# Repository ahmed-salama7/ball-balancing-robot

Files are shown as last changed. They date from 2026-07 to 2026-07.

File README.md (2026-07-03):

# Real-Time Ball-Balancing Robot

A closed-loop **ball-on-plate** balancing platform. A camera tracks a ball on a circular plate, and a **3-RRS parallel manipulator** driven by three servos tilts the plate to roll the ball back to the center — in real time.

A PC runs the computer-vision pipeline (OpenCV) and streams the ball's pixel coordinates over USB to an **STM32F103C8T6 "Blue Pill"**, which closes the loop with a **PID controller** and an **inverse-kinematics** solver that converts the desired plate tilt into the three servo angles.

<p align="center">
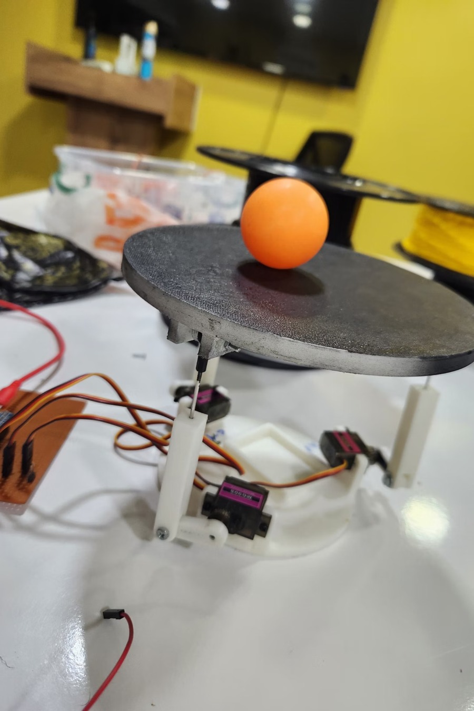
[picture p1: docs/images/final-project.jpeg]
Finished ball-balancing robot with ball centered on the plate
  
</p>

---

## Table of Contents

- [How It Works](#how-it-works)
- [Demo & Gallery](#demo--gallery)
- [Repository Structure](#repository-structure)
- [Hardware](#hardware)
  - [Bill of Materials](#bill-of-materials)
  - [Schematic & PCB](#schematic--pcb)
  - [Board Connectors](#board-connectors)
  - [STM32 Pinout](#stm32-pinout)
  - [Power](#power)
  - [KiCad Source](#kicad-source)
- [Mechanical Design](#mechanical-design)
- [Computer Vision](#computer-vision)
- [Control System (PID)](#control-system-pid)
- [Inverse Kinematics](#inverse-kinematics)
- [System Modeling](#system-modeling)
- [Getting Started](#getting-started)
- [Tuning Guide](#tuning-guide)
- [Roadmap](#roadmap)
- [Team](#team)
- [License](#license)

---

## How It Works

The system is a continuous feedback loop running at **50 Hz**:

```mermaid
flowchart LR
    CAM([USB Camera]) --> CV

    subgraph PC["PC — Python / OpenCV"]
        direction TB
        CV["Ball Detection<br/>(HoughCircles)"] --> TX["Serial TX<br/>'x,y' @ 50 Hz"]
    end

    TX -->|"USB CDC<br/>Virtual COM @ 115200"| RX

    subgraph STM["STM32F103C8T6 — Blue Pill"]
        direction TB
        RX["USB CDC RX<br/>parse x,y"] --> PID["PID Controller"]
        PID -->|"tilt slopes (nx, ny)"| IK["Inverse Kinematics<br/>(3-RRS)"]
        IK -->|"θA, θB, θC"| PWM["TIM2 PWM<br/>50 Hz"]
    end

    PWM --> SA([Servo A])
    PWM --> SB([Servo B])
    PWM --> SC([Servo C])

    SA --> PLATE[/Tilting Platform/]
    SB --> PLATE
    SC --> PLATE

    PLATE -.->|"ball rolls toward center"| CAM
```

| Stage | Where | What happens |
|---|---|---|
| **1. Detect** | PC (Python) | A webcam frame is processed with OpenCV. The ball is found with a Hough circle transform, returning its `(x, y)` pixel position. |
| **2. Transmit** | PC → MCU | The coordinates are sent as an ASCII string `"x,y\n"` over a USB CDC virtual COM port at up to 50 Hz. |
| **3. Compute error** | STM32 | The pixel error is `error = center − ball`, where the center is `(320, 240)`. |
| **4. PID** | STM32 | A discrete PID controller turns the error into a desired **platform tilt slope** `(nx, ny)`, saturated for safety. |
| **5. Inverse kinematics** | STM32 | The tilt slope and platform height are converted into three servo joint angles `(θA, θB, θC)`. |
| **6. Actuate** | STM32 → servos | Angles are mapped to PWM and written to the three servos via TIM2, tilting the plate so the ball rolls back toward center. |

---

## Demo & Gallery

| The finished robot | Assembled controller board |
|:---:|:---:|
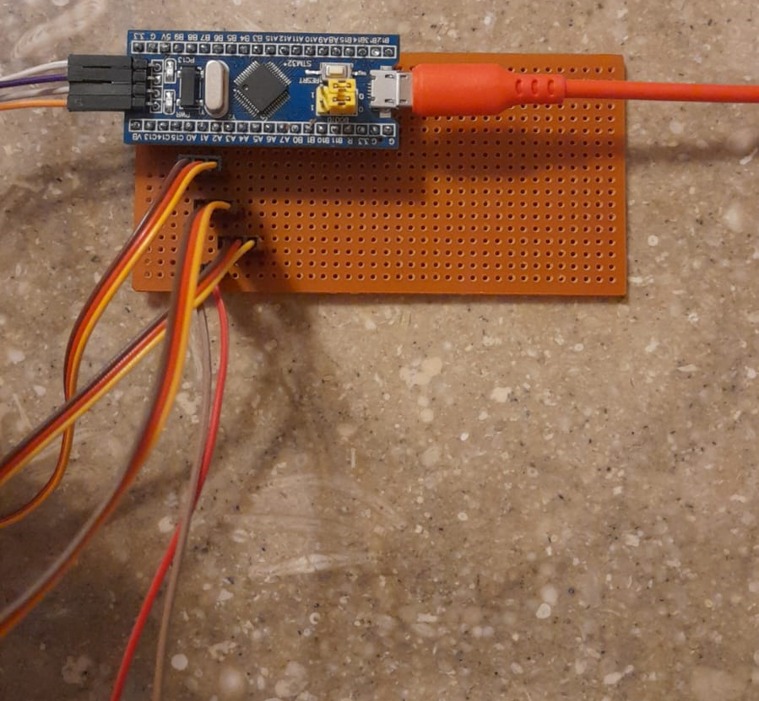
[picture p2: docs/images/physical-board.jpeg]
|  |  |

| Bench setup | CAD — isometric | CAD — side |
|:---:|:---:|:---:|
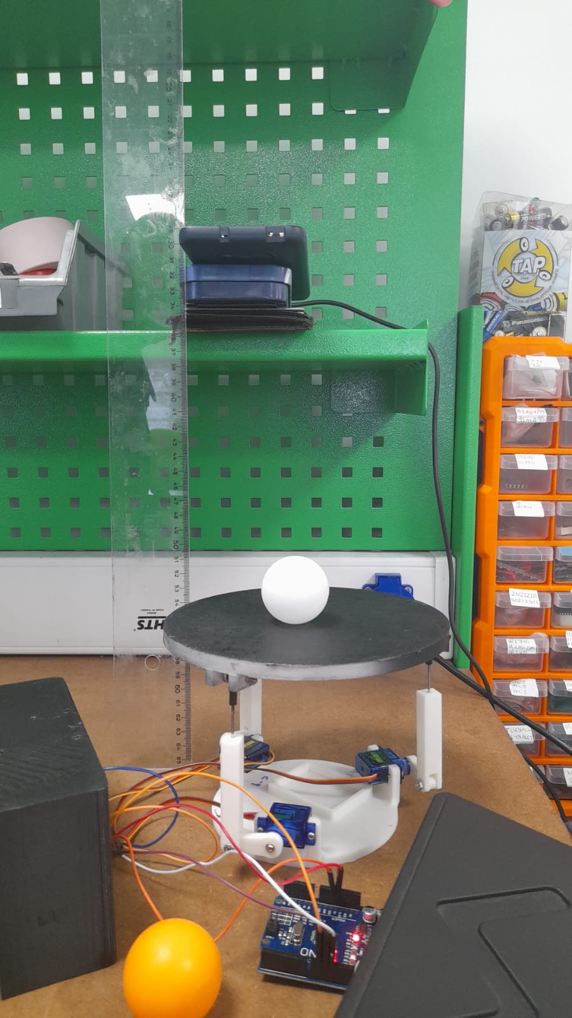
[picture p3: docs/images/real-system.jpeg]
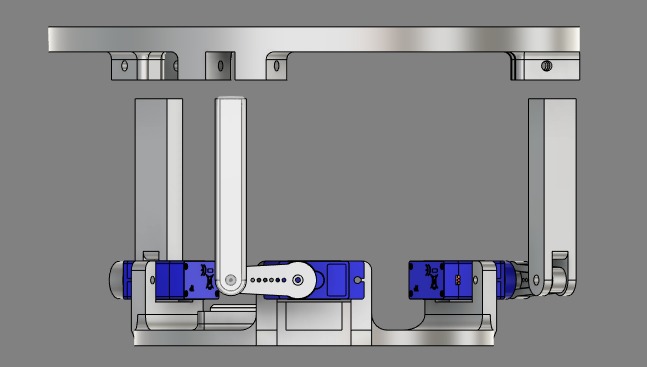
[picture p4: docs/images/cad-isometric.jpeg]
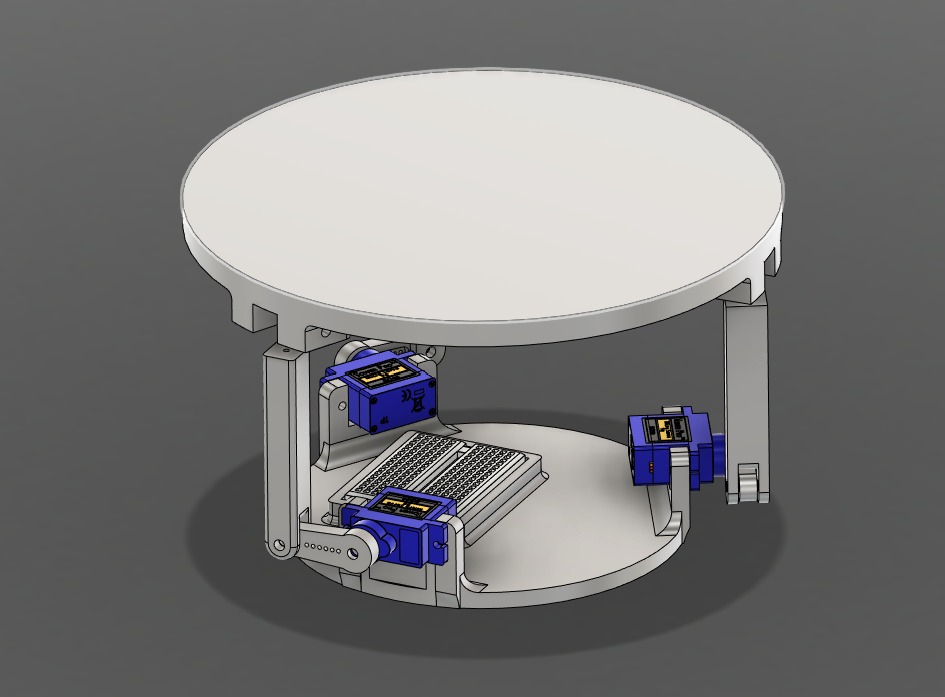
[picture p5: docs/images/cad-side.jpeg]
|  |  |  |

> A full project presentation (mechanical design, system identification, Simulink models, results) is included at
> [`docs/presentation/Real-Time-Ball-Balancing-Robot.pptx`](docs/presentation/Real-Time-Ball-Balancing-Robot.pptx).

---

## Repository Structure

```
ball-balancing-robot/
├── README.md                     ← you are here
├── LICENSE
├── .gitignore
│
├── vision/                       # PC-side computer vision (Python)
│   ├── ball_tracker.py           # main tracker: detects ball, streams coords over serial
│   ├── circle_calibration.py     # helper to align the camera with the physical plate
│   ├── requirements.txt
│   └── README.md
│
├── firmware/
│   ├── arduino/                  # Reference prototype (Arduino / STM32duino)
│   │   ├── ball_balancer/
│   │   │   ├── ball_balancer.ino # control loop: serial → PID → IK → servos
│   │   │   ├── InverseKinematics.cpp
│   │   │   └── InverseKinematics.h
│   │   └── README.md
│   │
│   └── stm32/                     # Deployed firmware (STM32CubeIDE / HAL)
│       ├── Core/                  # application code (main.c) + HAL init
│       ├── Drivers/               # CMSIS + STM32F1xx HAL drivers
│       ├── Middlewares/           # ST USB Device library
│       ├── USB_DEVICE/            # USB CDC (virtual COM) app layer
│       ├── usb_cdc.ioc            # CubeMX configuration (TIM2 PWM + USB CDC)
│       ├── STM32F103C8TX_FLASH.ld
│       ├── .cproject / .project / .mxproject
│       └── README.md
│
├── hardware/
│   ├── README.md                 # PCB, power, wiring notes
│   └── kicad/                     # editable KiCad PCB source (open the .kicad_pro)
│       ├── <project>.kicad_pro   #   project file
│       ├── <project>.kicad_sch   #   schematic
│       ├── <project>.kicad_pcb   #   board layout
│       └── <project>.kicad_prl   #   local settings
│
└── docs/
    ├── images/                   # photos, CAD renders, schematic, PCB
    └── presentation/             # full project slide deck (.pptx)
```

---

## Hardware

### Bill of Materials

| Qty | Component | Notes |
|:---:|---|---|
| 1 | **STM32F103C8T6 "Blue Pill"** | Main controller. 72 MHz Cortex-M3. |
| 3 | **9g micro servos** | Drive the three RRS legs (e.g. SG90 / MG90S class). |
| 1 | **ST-Link V2** | For flashing & SWD debugging the Blue Pill. |
| 1 | **USB webcam** | Mounted above the plate, looking straight down. |
| 1 | **External 5 V power adapter** | Powers the servos (do **not** power servos from the Blue Pill's regulator). |
| 1 | **Custom PCB** | Routes signals and 5 V power to the servos (KiCad design). |
| 1 | **Circular plate + ball** | Flat plate where the ball rolls (a standard ping-pong ball). |
| 1 | **Perfboard / protoboard** | The final build hand-wires the Blue Pill and servo headers on perfboard (see note below). |
| — | **3D-printed parts** | Base, legs, servo horns, platform mounts. |

### Schematic & PCB

| Schematic | PCB layout | PCB 3D render |
|:---:|:---:|:---:|
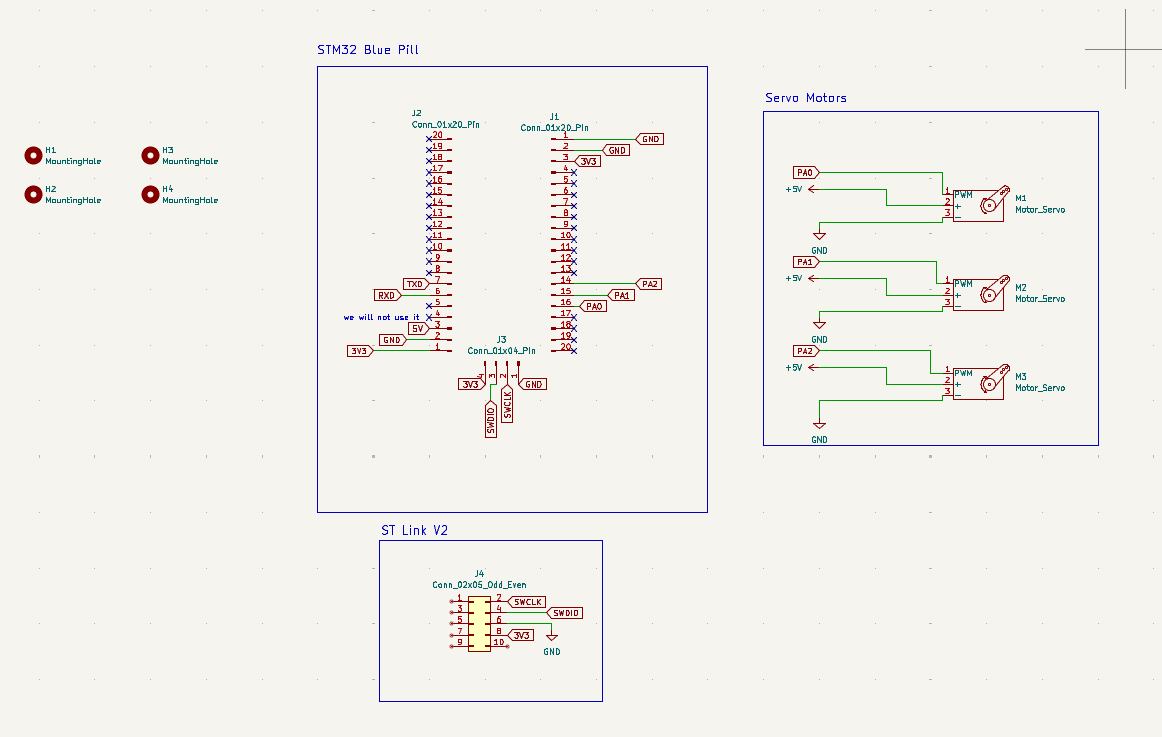
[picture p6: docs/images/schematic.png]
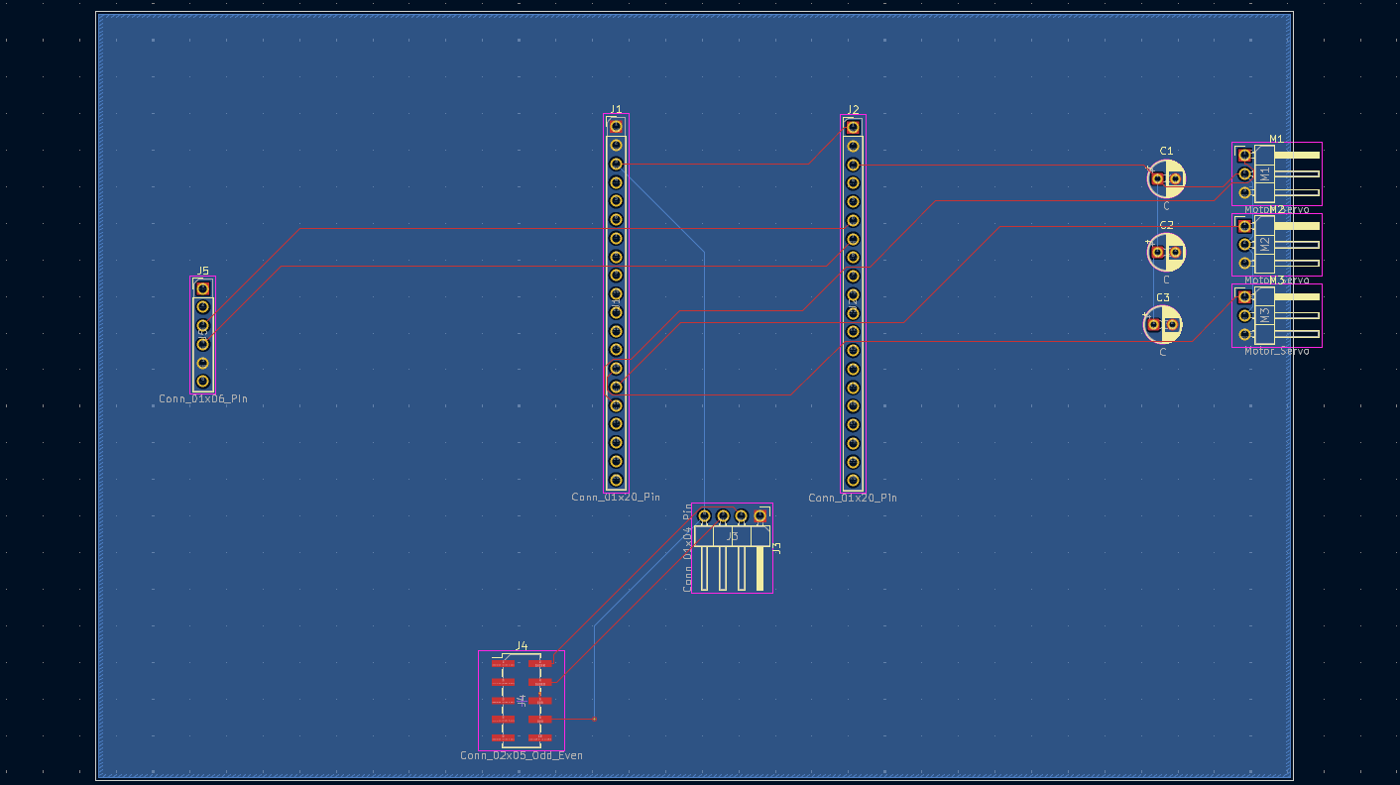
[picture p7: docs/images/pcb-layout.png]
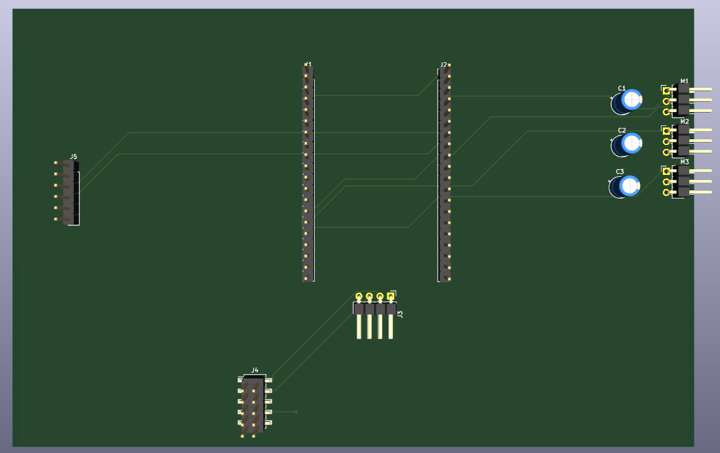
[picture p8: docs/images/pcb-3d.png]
|  |  |  |

The custom PCB acts as a carrier/breakout for the Blue Pill (`J1`, `J2`), the servo headers (`M1`–`M3`), the ST-Link SWD header (`J4`), and an auxiliary header (`J5`), with the servo signal lines and a shared external 5 V/GND rail.

> **Design vs. build.** The board above is the **KiCad design**. The **final working build** uses an STM32 Blue Pill hand-soldered onto perfboard with jumper wires out to the three servos and the ST-Link — the images below. The pin assignments are identical; only the physical routing differs.
>
> <p align="center">
>   STM32 Blue Pill hand-wired on perfboard
> </p>

### Board Connectors

The board is a carrier/breakout that fans the Blue Pill out to the three servos and the ST-Link, distributing the external 5 V servo power and a common ground.

| Ref | Role |
|-----|---|
| `J1`, `J2` | Blue Pill headers (2× 20-pin) that carry the MCU onto the board. |
| `M1`, `M2`, `M3` | Servo connectors (signal / +5 V / GND) for legs A, B, C. |
| `J4` | ST-Link V2 SWD header (SWDIO, SWCLK, 3V3, GND). |
| `J5` | Auxiliary header. |
| `C1`–`C3` | Decoupling for the servo power rail. |

### STM32 Pinout

The firmware uses **TIM2** for three hardware-PWM servo channels and the on-chip **USB peripheral** as a CDC virtual COM port.

| Pin | Peripheral / Function | Connected to |
|-----|---|---|
| **PA0** | `TIM2_CH1` — PWM | Servo **A** (Leg A / M1) signal |
| **PA1** | `TIM2_CH2` — PWM | Servo **B** (Leg B / M2) signal |
| **PA3** | `TIM2_CH4` — PWM | Servo **C** (Leg C / M3) signal |
| **PA11** | `USB_DM` | USB D− → PC |
| **PA12** | `USB_DP` | USB D+ → PC |
| **PA13** | `SWDIO` | ST-Link V2 |
| **PA14** | `SWCLK` | ST-Link V2 |
| **PC13** | GPIO output | On-board LED |
| **5V (ext.)** | Power | Servo VCC (external 5 V adapter) |
| **GND** | Ground | Common ground (PC, MCU, servos) |

**PWM timing.** TIM2 is clocked so that one count = 1 µs (`Prescaler = 72−1`) with a period of 20,000 counts (`Period = 20000−1`) → a **20 ms / 50 Hz** servo frame. Pulse widths in the ~1000–2000 µs range set servo position.

> **Note on pin numbering.** The KiCad schematic labels the servos on PA0/PA1/**PA2**, while the shipped CubeMX configuration drives them on PA0/PA1/**PA3** (TIM2 channels 1, 2, 4). The firmware is the source of truth — use **PA0 / PA1 / PA3**.

### Power

> ⚠️ **Never** power the servos from the Blue Pill's on-board regulator — three servos under load can momentarily draw amps and will brown out the MCU.

- Use a dedicated **5 V adapter** sized for your servos.
- Tie **all grounds together** — PC USB ground, MCU ground, and the servo-supply ground — so the PWM signals share a common reference.

### KiCad Source

The board's editable source lives in [`hardware/kicad/`](hardware/kicad/):

| File | What it is |
|---|---|
| `*.kicad_pro` | KiCad project file — open this one. |
| `*.kicad_sch` | Schematic. |
| `*.kicad_pcb` | PCB layout. |
| `*.kicad_prl` | Project-local settings. |

Open the `.kicad_pro` in **KiCad 7 or later** to view or edit the schematic and board, or to export gerbers for fabrication. Auto-generated backups, autosaves, and caches are excluded by `.gitignore`.

---

## Mechanical Design

The platform is a **3-RRS parallel manipulator** (each leg: a base **R**evolute joint actuated by a servo → a link → a **S**pherical joint at the moving plate; "RRS" denotes the joint chain per leg). Three legs spaced 120° apart give the plate the two tilt degrees of freedom needed to steer the ball, plus a controllable height.

The inverse-kinematics solver is parameterized by four lengths (all in **centimeters**), set in the firmware:

| Symbol | Meaning | Value (cm) |
|:---:|---|:---:|
| `d` | Base center → corner distance | 5.70 |
| `e` | Platform center → corner distance | 8.50 |
| `f` | Link 1 length (servo horn) | 3.10 |
| `g` | Link 2 length (connecting rod) | 9.66 |
| `hz` | Baseline platform height | 10.25 |

**Servo calibration** (neutral angle = plate level), from the firmware:

| | Leg A | Leg B | Leg C |
|---|:---:|:---:|:---:|
| Neutral angle | 74° | 97° | 83° |
| Direction sign | +1 | +1 | +1 |
| Safe travel limits | \[40°, 100°\] | \[40°, 100°\] | \[40°, 100°\] |

> Design goals: a stiff plate, **known neutral geometry** so the IK baseline is exact, and conservative servo travel limits so the mechanism can never drive itself into a hard stop.

---

## Computer Vision

The vision script ([`vision/ball_tracker.py`](vision/ball_tracker.py)) detects the ball and streams its position. The pipeline:

1. **Pre-process** — convert the frame to grayscale and apply a 9×9 Gaussian blur to suppress noise.
2. **Detect** — run a Hough circle transform (`cv2.HoughCircles`) to find circular candidates within a radius band.
3. **Validate** — for the white ball, the mean brightness *inside* each candidate circle is checked, rejecting non-ball circles. _(An alternative HSV color-threshold path can be used for a colored ball — see the slide deck.)_
4. **Overlay & calibrate** — a fixed reference circle is drawn at the image center `(320, 240)` so the camera frame can be physically aligned with the plate. Use [`circle_calibration.py`](vision/circle_calibration.py) to do this alignment.
5. **Transmit** — when the ball is found, the script sends `"x,y\n"` over the serial port (`COM11` @ 115200 by default). A status overlay shows the live connection state and detected pixel coordinates.

> **Set your serial port** at the top of `ball_tracker.py` (`serial_port = "COM11"`). On Linux/macOS this looks like `/dev/ttyACM0` or `/dev/tty.usbmodemXXXX`.

---

## Control System (PID)

The controller runs on a fixed sample time of $\Delta t = 20\ \text{ms}$ (50 Hz). The error is the offset of the ball from the image center, computed independently on each axis:

$$
e_x = c_x - b_x, \qquad e_y = c_y - b_y
$$

where $(c_x, c_y) = (320, 240)$ px is the target center and $(b_x, b_y)$ is the detected ball position.

A discrete PID is evaluated per axis, using **trapezoidal integration**:

$$
I_k = I_{k-1} + \left(e_k + e_{k-1}\right)\,\Delta t
$$

$$
D_k = \frac{e_k - e_{k-1}}{\Delta t}
$$

$$
u_k = K_p\, e_k + K_i\, I_k + K_d\, D_k
$$

The output $u_k$ is the **commanded plate tilt slope** $(n_x, n_y)$, clamped to a safe range to bound how far the plate can tilt:

$$
u_k \in \left[-s_{\max},\ +s_{\max}\right], \qquad s_{\max} = 0.6
$$

If no fresh coordinate arrives within ~500 ms, the controller commands the plate flat as a failsafe.

**Gains.** The PID gains were tuned iteratively; the value of starting from a small proportional gain and adding derivative damping is documented inline in the firmware. They are exposed as plain constants (`kp`, `ki`, `kd`) so you can re-tune for your own servos, plate friction, and camera latency — see the [Tuning Guide](#tuning-guide).

---

## Inverse Kinematics

Inverse kinematics converts the **desired plate pose** — a unit normal vector $\hat{n} = (n_x, n_y, n_z)$ and a height $h_z$ — into the **servo angle required for each leg**.

For each leg the solver evaluates a closed-form expression (derived from the leg geometry $d, e, f, g$) and returns the joint angle $\theta$:

$$
\theta_{\text{leg}} = \texttt{machine.theta}(\text{leg},\ h_z,\ n_x,\ n_y)
$$

The geometric angle is then mapped to a servo command using the per-leg neutral and direction calibration:

$$
\theta_{\text{servo}} = \theta_{\text{neutral}} + s \cdot \mathrm{round}\!\left(\theta - \theta_0\right)
$$

where $\theta_0$ is the baseline angle for a perfectly level plate (computed once at startup) and $s \in \{-1, +1\}$ sets the rotation direction. Each result is finally constrained to the safe travel limits before being written to the servo.

**End-to-end signal flow:**

$$
\underbrace{(b_x, b_y)}_{\text{pixels}} \;\xrightarrow{\text{PID}}\; \underbrace{(n_x, n_y)}_{\text{tilt slopes}} \;\xrightarrow{\text{IK}}\; \underbrace{(\theta_A, \theta_B, \theta_C)}_{\text{joint angles}} \;\xrightarrow{\text{map + PWM}}\; \text{servos}
$$

The full derivation lives in [`InverseKinematics.cpp`](firmware/arduino/ball_balancer/InverseKinematics.cpp).

---

## System Modeling

Beyond hand-tuning, the servos were characterized to enable model-based control design (see the slide deck for figures):

- **Data collection** — the servo's built-in position feedback was logged as `(time [ms], commanded angle [deg], measured angle [deg])`.
- **System identification** — a black-box fit produced a transfer function (settling-time / `Ts`) model of the servo response.
- **Simulink** — the closed loop was modeled both *without* and *with* the inverse-kinematics block, and the step responses were compared against the physical system.

---

## Getting Started

### 1. Vision (PC)

```bash
cd vision
pip install -r requirements.txt
# Edit ball_tracker.py and set serial_port to your board's COM/tty port
python ball_tracker.py
```

A window opens showing the camera feed, the reference circle, the detection, and an `STM: Connected/Disconnected` overlay. Press **`q`** or **`Esc`** to quit. Use `circle_calibration.py` first if you need to physically align the camera with the plate.

### 2. Firmware — STM32 (recommended / deployed)

1. Open **STM32CubeIDE** → *File ▸ Open Projects from File System…* → select `firmware/stm32/`.
2. (Optional) Open `usb_cdc.ioc` in CubeMX to review the TIM2 + USB CDC configuration.
3. Build, connect the **ST-Link V2** to the SWD header, and flash.
4. The board enumerates as a USB **Virtual COM Port** — note the port number and put it in `ball_tracker.py`.

> ⚠️ **Before this builds**, the generated source folders (`Core/`, `Drivers/`, `Middlewares/`, `USB_DEVICE/`) must be present. See **[`firmware/stm32/README.md`](firmware/stm32/README.md)** — those folders are *not* committed here yet, and the README explains exactly how to add them.

### 3. Firmware — Arduino (reference prototype)

```text
Open firmware/arduino/ball_balancer/ball_balancer.ino in the Arduino IDE
→ install the Servo library
→ select your board, then upload
```

This sketch contains the same control logic (PID + inverse kinematics) and is the easiest way to read and understand the algorithm. See [`firmware/arduino/README.md`](firmware/arduino/README.md).

---

## Tuning Guide

Re-tune for your own hardware in this order:

1. **Camera alignment & center.** Run `circle_calibration.py`. Make sure the reference circle is concentric with the plate and `(320, 240)` is the true target. A miscalibrated center is the #1 cause of a ball that "parks" off-center.
2. **Servo neutrals.** With the plate empty, adjust `servoNeutralA/B/C` until the plate is dead level. The IK baseline depends on this.
3. **Proportional gain `kp`.** Start small. Increase until the ball is actively pushed toward center, then back off just before it oscillates.
4. **Derivative gain `kd`.** Add a little to damp overshoot and settle the ball faster.
5. **Integral gain `ki`.** Add a *very* small amount only if the ball consistently settles slightly off-center. Too much integral causes slow oscillation/wind-up.
6. **Safety.** Keep `maxSlope` and the servo travel limits conservative until the loop is stable.

---

## Roadmap

Ideas for extending the project:

- [ ] Trajectory tracking (drive the ball along a circle/figure-8, not just to center)
- [ ] On-board vision (move detection to an MCU/SBC to remove the PC)
- [ ] Auto-tuning or model-based (LQR/state-feedback) control using the identified servo model
- [ ] Latency compensation / ball-velocity estimation (Kalman filter)
- [ ] Publish the KiCad source and 3D-printable STL files

---

## Team

**Team 11**

| Discipline | Member(s) |
|---|---|
| Control | Mohamed Haroun, Abdulrahman Alabed |
| Computer Vision | Taqi Aldeen |
| Electronics | Ahmed Salama |
| Mechanical | Salah Hamwi |
| Embedded Systems | Abdelaziz Hassan |

---

## License

Released under the **MIT License** — see [`LICENSE`](LICENSE).

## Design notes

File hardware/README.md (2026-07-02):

# Hardware

The custom PCB and wiring for the ball-balancing platform.

| Schematic | PCB layout | 3D render |
|:---:|:---:|:---:|
| [`schematic.png`](../docs/images/schematic.png) | [`pcb-layout.png`](../docs/images/pcb-layout.png) | [`pcb-3d.png`](../docs/images/pcb-3d.png) |

> **Design vs. build.** The KiCad board above is the *design*. The **final working build** hand-wires an STM32 Blue Pill on perfboard with jumper wires to the servos and ST-Link (same pin assignments, different physical routing):
>
> 

## What the board does

The PCB is a carrier/breakout that connects the Blue Pill to the three servos and the ST-Link, distributing the external 5 V servo power and a common ground.

| Ref | Role |
|-----|---|
| `J1`, `J2` | Blue Pill headers (2× 20-pin), carrying the MCU into the board. |
| `M1`, `M2`, `M3` | Servo connectors (signal / +5 V / GND) for legs A, B, C. |
| `J4` | ST-Link V2 SWD header (SWDIO, SWCLK, 3V3, GND). |
| `J5` | Auxiliary header. |
| `C1`–`C3` | Decoupling for the servo power rail. |

## Connections at a glance

| Signal | STM32 pin | Goes to |
|---|---|---|
| Servo A PWM | PA0 (TIM2_CH1) | `M1` signal |
| Servo B PWM | PA1 (TIM2_CH2) | `M2` signal |
| Servo C PWM | PA3 (TIM2_CH4) | `M3` signal |
| SWD | PA13 / PA14 | `J4` (ST-Link) |
| USB | PA11 / PA12 | Blue Pill USB → PC |
| Servo power | — | External **5 V** adapter → `M1/M2/M3` V+ |
| Ground | GND | Common to MCU, servos, and adapter |

> See the main [README pinout note](../README.md#stm32-pinout): the schematic labels servos on PA0/PA1/**PA2**, but the firmware drives PA0/PA1/**PA3**. Follow the firmware.

## ⚠️ Power

- **Never** power the servos from the Blue Pill's on-board regulator — three servos under load can momentarily draw amps and will brown out the MCU.
- Use a dedicated **5 V adapter** sized for your servos, and tie all grounds together (PC USB ground, MCU ground, servo-supply ground).

## To add

The KiCad source (`.kicad_pro`, `.kicad_sch`, `.kicad_pcb`) and any gerbers are not yet committed. Drop them in this folder so others can fabricate or modify the board.

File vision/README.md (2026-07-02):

# Vision — Ball Tracking (PC)

The PC-side computer-vision pipeline. It detects the ball in a webcam stream and streams its pixel coordinates to the STM32 over a USB serial (virtual COM) link.

## Files

| File | Purpose |
|---|---|
| `ball_tracker.py` | Main program. Detects the ball, draws overlays, and sends `"x,y\n"` over serial. |
| `circle_calibration.py` | Standalone helper that draws a circle + center dot on the camera feed so you can physically align the camera with the plate. Run this first. |
| `requirements.txt` | Python dependencies. |

## Setup

```bash
pip install -r requirements.txt
python ball_tracker.py
```

Press **`q`** or **`Esc`** to quit. A live overlay shows the serial connection state (`STM: Connected/Disconnected`) and the detected ball coordinates.

## Configuration

Edit the constants at the top of `ball_tracker.py`:

| Constant | Default | Meaning |
|---|---|---|
| `serial_port` | `"COM11"` | Serial port of the STM32 virtual COM. Linux/macOS: `/dev/ttyACM0`, `/dev/tty.usbmodemXXXX`. |
| `baud_rate` | `115200` | Must match the firmware. |
| `min_r`, `max_r` | `50`, `70` | Hough circle radius band (pixels). Tune to your ball size & camera distance. |

The detection also has tunables inside `find_white_ball_center()`:
- `cv2.HoughCircles` parameters (`dp`, `minDist`, `param1`, `param2`)
- the brightness gate (`mean_inside > 200`) that distinguishes the white ball from other circles.

## How detection works

1. Convert frame to grayscale, blur with a 9×9 Gaussian.
2. `cv2.HoughCircles` finds circular candidates within the radius band.
3. For each candidate, the mean brightness *inside* the circle is measured; only bright (white-ball) circles pass.
4. The accepted circle's center `(x, y)` is sent as `"x,y\n"`.
5. A fixed **reference circle** is drawn at `(320, 240)` every frame to mark the target center for alignment.

> **Colored-ball variant:** the project also explored an HSV color-threshold approach (isolating an orange ball) before the circle transform. See the slide deck in `docs/presentation/` for that pipeline's parameters.

## Protocol

Plain ASCII, newline-terminated, one message per detection:

```
320,240\n
318,235\n
...
```

The firmware parses both `"x,y"` and `"(x,y)"` forms.

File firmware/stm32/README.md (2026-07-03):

# Firmware — STM32 (Deployed)

The deployed firmware for the **STM32F103C8T6 "Blue Pill"**, built with **STM32CubeIDE** (HAL). It receives ball coordinates over a USB CDC virtual COM port, runs the PID + inverse-kinematics control loop, and drives the three servos with hardware PWM on TIM2.

## Project layout

This is the **complete** CubeIDE project — open it and build. The main pieces:

| Path | Contents |
|---|---|
| `Core/` | Application code — `Src/main.c` (control loop) plus HAL init and interrupt handlers. |
| `Drivers/` | CMSIS + STM32F1xx HAL drivers. |
| `Middlewares/` | ST USB Device library. |
| `USB_DEVICE/` | USB CDC (virtual COM) app layer. |
| `usb_cdc.ioc` | CubeMX configuration (TIM2 PWM + USB CDC) — open to review peripherals. |
| `STM32F103C8TX_FLASH.ld` | Linker script. |
| `.cproject` / `.project` / `.mxproject` | CubeIDE project files. |

> **Where the logic lives:** the PID + inverse-kinematics control loop is in `Core/Src/main.c`, and the callback that parses incoming `"x,y\n"` coordinates is `CDC_Receive_FS` in `USB_DEVICE/App/usbd_cdc_if.c`. The same reference algorithm is mirrored in the Arduino sketch under [`../arduino/`](../arduino/).
>
> If you ever need to regenerate the HAL/USB skeleton, open `usb_cdc.ioc` in CubeMX and generate code — edits kept inside the `/* USER CODE */` blocks are preserved.

## Configuration summary (from `usb_cdc.ioc`)

| Setting | Value |
|---|---|
| MCU | STM32F103C8T6 (LQFP48) |
| System clock | 72 MHz (HSE 8 MHz crystal × PLL9) |
| USB clock | 48 MHz |
| **TIM2** | PWM, `Prescaler = 72−1`, `Period = 20000−1` → **50 Hz**, 1 µs resolution |
| TIM2_CH1 → **PA0** | Servo A PWM |
| TIM2_CH2 → **PA1** | Servo B PWM |
| TIM2_CH4 → **PA3** | Servo C PWM |
| **USB** | Device, **CDC** class (Virtual COM Port, "STM32 Virtual Port") |
| USB_DM / USB_DP | PA11 / PA12 |
| SWD | PA13 (SWDIO) / PA14 (SWCLK) |
| PC13 | GPIO output (on-board LED) |

## Build & flash

1. **STM32CubeIDE** → *File ▸ Open Projects from File System…* → select this `stm32/` folder.
2. **Build** (hammer icon).
3. Connect **ST-Link V2** to the SWD header, then **Run/Debug** (uses `usb_cdc Debug.launch`).
4. After flashing, plug the Blue Pill's USB into the PC — it enumerates as a **Virtual COM Port**. Put that port name in `vision/ball_tracker.py`.

## Notes

- Servos draw far more current than the Blue Pill's regulator can supply — power them from the **external 5 V adapter**, sharing a common ground.
- The CDC receive callback (`CDC_Receive_FS` in `usbd_cdc_if.c`) is where incoming `"x,y\n"` bytes are handled and fed to the controller.

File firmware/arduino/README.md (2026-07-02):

# Firmware — Arduino (Reference Prototype)

This is the **reference implementation** of the control loop, written for the Arduino framework. It is the clearest way to read and understand the algorithm (serial parsing → PID → inverse kinematics → servo output). The deployed build runs on the STM32 (see [`../stm32/`](../stm32/)).

## Files

| File | Purpose |
|---|---|
| `ball_balancer.ino` | Main sketch: serial RX, PID controller, IK call, servo mapping, 50 Hz loop. |
| `InverseKinematics.cpp` | The `Machine` class — closed-form IK for the 3-RRS platform. |
| `InverseKinematics.h` | Class/constants declaration. |

> Arduino requires the main sketch and its folder to share a name, so `main.ino` was renamed to `ball_balancer.ino` inside the `ball_balancer/` folder. The IK files sit alongside it in the same sketch folder.

## Build & upload

1. Open `ball_balancer/ball_balancer.ino` in the Arduino IDE.
2. Install the **Servo** library (Library Manager).
3. Select your board and port, then upload.

## What the code does

```
loop():
  read serial bytes → assemble a line → parse "x,y"
  PID_compute(x, y)              # error = center - ball, discrete PID per axis
  moveTo(platformHz, -out_x, -out_y)
      → machine.theta(...) for legs A, B, C   # inverse kinematics
      → map θ to servo angle, constrain to safe travel
      → servo.write(...)
  (failsafe: if no fresh data for ~500 ms, command the plate flat)
```

## Key parameters (top of `ball_balancer.ino`)

| Parameter | Meaning |
|---|---|
| `Machine machine(5.7, 8.5, 3.1, 9.66)` | IK geometry `(d, e, f, g)` in cm. |
| `servoPinA/B/C` (`9`, `10`, `11`) | Servo signal pins (Arduino framework numbering). |
| `servoNeutralA/B/C` | Per-servo neutral angle for a level plate. |
| `servoMin`, `servoMax` | Safe travel limits. |
| `kp`, `ki`, `kd` | PID gains (commented alternatives included). |
| `platformHz` | Baseline platform height (cm) for the IK. |
| `maxSlope` | Tilt-slope saturation for safety. |
| `LOOP_PERIOD_MS` | Control period (20 ms → 50 Hz). |
| `centerX`, `centerY` | Target pixel center (`320`, `240`). |

> **Pin numbering differs by target.** This sketch uses Arduino pins `9/10/11`. The STM32 HAL firmware uses hardware-timer channels on **PA0 / PA1 / PA3**. Both drive the same three servos — see the main [README pinout](../../README.md#stm32-pinout).

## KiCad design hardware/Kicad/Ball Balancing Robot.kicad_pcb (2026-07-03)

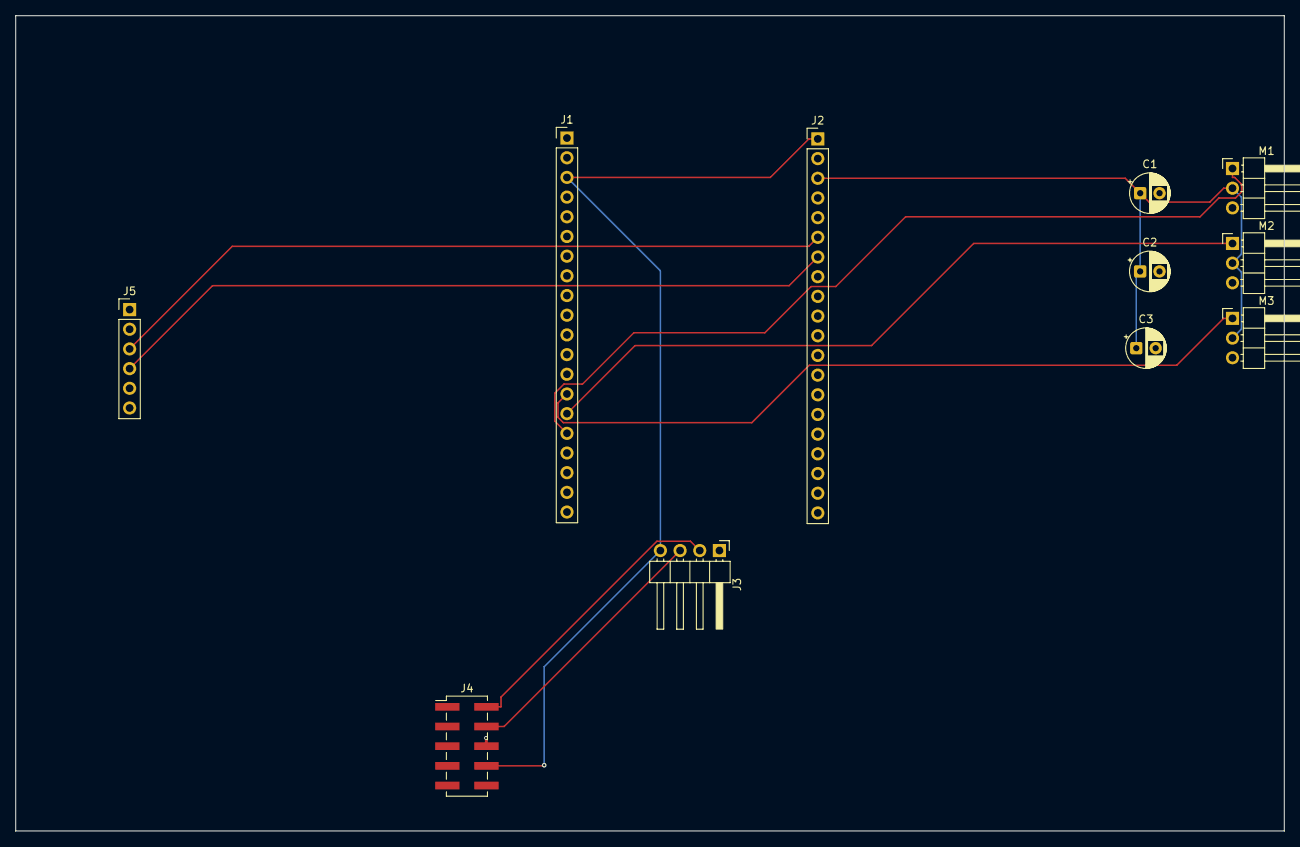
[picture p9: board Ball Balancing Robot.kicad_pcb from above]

Board: 2 copper layers, 163.7 x 105.2 mm, 11 parts (0 on the bottom side), 10 nets.

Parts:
C1, C2, C3: C; CP_Radial_D5.0mm_P2.50mm
J1, J2: Conn_01x20_Pin; PinHeader_1x20_P2.54mm_Vertical
J3: Conn_01x04_Pin; PinHeader_1x04_P2.54mm_Horizontal
J4: Conn_02x05_Odd_Even; PinHeader_2x05_P2.54mm_Vertical_SMD
J5: Conn_01x06_Pin; PinHeader_1x06_P2.54mm_Vertical
M1, M2, M3: Motor_Servo; PinHeader_1x03_P2.54mm_Horizontal

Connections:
3V3: J1.3, J2.1, J3.4, J4.8
5V: C1.1, C2.1, C3.1, J2.3, M1.2 (+), M2.2 (+), M3.2 (+)
GND: C1.2, C2.2, C3.2, J1.1, J1.2, J2.2, J3.1, J4.6, J5.5, M1.3 (-), M2.3 (-), M3.3 (-)
PA0: J1.16, M1.1 (PWM)
PA1: J1.15, M2.1 (PWM)
PA2: J1.14, M3.1 (PWM)
RXD: J2.6, J5.3
SWCLK: J3.2, J4.2
SWDIO: J3.3, J4.4
TXD: J2.7, J5.4

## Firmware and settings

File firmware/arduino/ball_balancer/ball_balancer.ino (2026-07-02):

#include <Servo.h>
#include "InverseKinematics.h"
#include <math.h>

// ----------------- Machine geometry (cm) -----------------
Machine machine(5.7, 8.5, 3.1, 9.66); // (d, e, f, g)

// ----------------- Servo pins & objects -----------------
const int servoPinA = 9;
const int servoPinB = 10;
const int servoPinC = 11;
Servo servoA, servoB, servoC;

// ----------------- Servo calibration -----------------
int servoNeutralA = 74;
int servoNeutralB = 97;
int servoNeutralC = 83;

int servoSignA = 1;
int servoSignB = 1;
int servoSignC = 1;

const int servoMin = 40; // safe travel lower bound
const int servoMax = 100; // safe travel upper bound

// ----------------- PID controller -----------------
// double kp = 0.0009; // proportional per pixel (Base acceptle response but high overshoot bubt can be stable with no hzat)
// double ki = 0.0;
// double kd = 0.0001;
// double kp = 0.0008; // proportional per pixel //form the above less overshoot but still oscilation a touch of it  
// double ki = 0.00000001;
// double kd = 0.0001;
double kp = 0.0004; // 
double ki = 0.0;
double kd = 0.0000;
double errorArr[2] = { 0, 0 }, errorPrev[2] = { 0, 0 }, integr[2] = { 0, 0 }, deriv[2] = { 0, 0 }, out[2] = { 0, 0 };

// baseline platform height (cm) used by IK — tune if needed
double platformHz = 10.25;

// max tilt slope (safety)
const double maxSlope = 0.6;

// loop timing
const unsigned long LOOP_PERIOD_MS = 20UL; // 50 Hz

// baseline IK thetas for flat platform
double theta0A = 0, theta0B = 0, theta0C = 0;

// serial parsing helper
String serialLine = "";

// center of camera in pixels
const double centerX = 320;
const double centerY = 240;

// ----------------- Parse "(x,y)" from Python -----------------
bool parseXYfromLine(const String &s, double &xOut, double &yOut) {
  String tmp = s;
  tmp.trim(); // remove leading/trailing whitespace
  if (tmp.length() == 0) return false;

  // Allow either "(x,y)" or "x,y" (with optional spaces)
  if (tmp.startsWith("(") && tmp.endsWith(")")) {
    tmp = tmp.substring(1, tmp.length() - 1);
    tmp.trim();
  }

  int commaIndex = tmp.indexOf(',');
  if (commaIndex < 0) return false;

  String xs = tmp.substring(0, commaIndex);
  String ys = tmp.substring(commaIndex + 1);

  xs.trim();
  ys.trim();

  // If either is empty, fail
  if (xs.length() == 0 || ys.length() == 0) return false;

  xOut = xs.toDouble();
  yOut = ys.toDouble();

  // Optionally: check for NaN (toDouble returns 0 on failure, so best-effort)
  return true;
}

// ----------------- Map IK theta -> servo write -----------------
void moveTo(double hz, double nx, double ny) {
  if (nx > maxSlope) nx = maxSlope;
  if (nx < -maxSlope) nx = -maxSlope;
  if (ny > maxSlope) ny = maxSlope;
  if (ny < -maxSlope) ny = -maxSlope;

  double thetaA = machine.theta(0, hz, nx, ny);
  double thetaB = machine.theta(1, hz, nx, ny);
  double thetaC = machine.theta(2, hz, nx, ny);

  int servoAngleA = servoNeutralA + servoSignA * (int)round(thetaA - theta0A);
  int servoAngleB = servoNeutralB + servoSignB * (int)round(thetaB - theta0B);
  int servoAngleC = servoNeutralC + servoSignC * (int)round(thetaC - theta0C);

  servoAngleA = constrain(servoAngleA, servoMin, servoMax);
  servoAngleB = constrain(servoAngleB, servoMin, servoMax);
  servoAngleC = constrain(servoAngleC, servoMin, servoMax);

  servoA.write(servoAngleA);
  servoB.write(servoAngleB);
  servoC.write(servoAngleC);

  // debug
  Serial.print("Servo: ");
  Serial.print(servoAngleA);
  Serial.print(", ");
  Serial.print(servoAngleB);
  Serial.print(", ");
  Serial.println(servoAngleC);
}

// ----------------- PID controller -----------------
void PID_compute(double ballX_px, double ballY_px) {
  errorPrev[0] = errorArr[0];
  errorPrev[1] = errorArr[1];

  // error = center - ball position
  errorArr[0] = centerX - ballX_px;
  errorArr[1] = centerY - ballY_px;

  integr[0] += (errorArr[0] + errorPrev[0]) * (LOOP_PERIOD_MS / 1000.0);
  integr[1] += (errorArr[1] + errorPrev[1]) * (LOOP_PERIOD_MS / 1000.0);

  deriv[0] = (errorArr[0] - errorPrev[0]) / (LOOP_PERIOD_MS / 1000.0);
  deriv[1] = (errorArr[1] - errorPrev[1]) / (LOOP_PERIOD_MS / 1000.0);

  out[0] = kp * errorArr[0] + ki * integr[0] + kd * deriv[0];
  out[1] = kp * errorArr[1] + ki * integr[1] + kd * deriv[1];

  out[0] = constrain(out[0], -maxSlope, maxSlope);
  out[1] = constrain(out[1], -maxSlope, maxSlope);
}

void setup() {
  Serial.begin(115200);
  delay(50);

  servoA.attach(servoPinA);
  servoB.attach(servoPinB);
  servoC.attach(servoPinC);

  servoA.write(servoNeutralA);
  servoB.write(servoNeutralB);
  servoC.write(servoNeutralC);
  delay(300);

  theta0A = machine.theta(0, platformHz, 0.0, 0.0);
  theta0B = machine.theta(1, platformHz, 0.0, 0.0);
  theta0C = machine.theta(2, platformHz, 0.0, 0.0);

  Serial.println("Ball-Balancer ready. Waiting for Python pixel data...");
}

void loop() {
  static unsigned long lastLoop = 0;
  static unsigned long lastSerialTime = 0;
  unsigned long now = millis();

  while (Serial.available()) {
    char c = (char)Serial.read();
    if (c == '\r') continue;
    if (c == '\n') {
      String line = serialLine;
      serialLine = "";
      double bx, by;
      if (parseXYfromLine(line, bx, by)) {
        lastSerialTime = millis();
        PID_compute(bx, by);
        moveTo(platformHz, -out[0], -out[1]);
      }
    } else {
      serialLine += c;
      if (serialLine.length() > 200) serialLine = serialLine.substring(serialLine.length() - 200);
    }
  }

  if (millis() - lastLoop >= LOOP_PERIOD_MS) {
    lastLoop = millis();
    if (millis() - lastSerialTime < 500) {
      moveTo(platformHz, -out[0], -out[1]);
    } else {
      moveTo(platformHz, 0.0, 0.0);
    }
  }
}

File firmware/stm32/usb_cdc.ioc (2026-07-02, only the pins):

Mcu.UserName=STM32F103C8Tx
PA0-WKUP.Signal=S_TIM2_CH1_ETR
PA1.Signal=S_TIM2_CH2
PA11.Signal=USB_DM
PA12.Signal=USB_DP
PA13.Signal=SYS_JTMS-SWDIO
PA14.Signal=SYS_JTCK-SWCLK
PA3.Signal=S_TIM2_CH4
PC13-TAMPER-RTC.Signal=GPIO_Output
PD0-OSC_IN.Signal=RCC_OSC_IN
PD1-OSC_OUT.Signal=RCC_OSC_OUT

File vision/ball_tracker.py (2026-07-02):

import cv2
import numpy as np
import serial
import time
import sys
import signal

# globals so signal handler can access them
cap = None
ser = None

def find_white_ball_center(frame, min_r=45, max_r=70):
    gray = cv2.cvtColor(frame, cv2.COLOR_BGR2GRAY)
    blurred = cv2.GaussianBlur(gray, (9, 9), 0)
    circles = cv2.HoughCircles(
        blurred,
        method=cv2.HOUGH_GRADIENT,
        dp=1.2,
        minDist=100,
        param1=100,
        param2=30,
        minRadius=min_r,
        maxRadius=max_r
    )
    if circles is not None:
        circles = np.round(circles[0, :]).astype("int")
        for (x, y, r) in circles:
            mask = np.zeros_like(gray)
            cv2.circle(mask, (x, y), r, 255, thickness=-1)
            mean_inside = cv2.mean(gray, mask=mask)[0]
            if mean_inside > 200:
                return (x, y, r)
    return None

def cleanup(cap_obj, ser_obj):
    """Release camera, close windows, close serial (silent)."""
    try:
        if cap_obj is not None:
            cap_obj.release()
    except Exception:
        pass
    try:
        cv2.destroyAllWindows()
    except Exception:
        pass
    try:
        if ser_obj is not None and getattr(ser_obj, "is_open", False):
            ser_obj.close()
    except Exception:
        pass

def signal_handler(sig, frame):
    """Handle signals like Ctrl+C (SIGINT) silently."""
    cleanup(cap, ser)
    sys.exit(0)

if __name__ == "__main__":
    serial_port = "COM11"  # or your port, e.g. "COM3"
    baud_rate = 115200

    # Open serial (silent on failure)
    try:
        ser = serial.Serial(serial_port, baud_rate, timeout=1)
        time.sleep(2)
    except Exception:
        ser = None

    # Open camera
    cap = cv2.VideoCapture(0)
    if not cap.isOpened():
        cleanup(cap, ser)
        sys.exit(1)

    # Register signal handler
    signal.signal(signal.SIGINT, signal_handler)

    try:
        # keep last known ball coords (or None)
        ball_coords = None

        while True:
            ret, frame = cap.read()
            if not ret:
                break

            res = find_white_ball_center(frame, min_r=50, max_r=70)
            if res is not None:
                x, y, r = res
                ball_coords = (int(x), int(y))

                # draw detection
                cv2.circle(frame, (int(x), int(y)), int(r), (0, 255, 0), 2)
                cv2.circle(frame, (int(x), int(y)), 2, (0, 0, 255), 3)

                # send as "x,y" (no parentheses), newline terminated
                if ser is not None and getattr(ser, "is_open", False):
                    data_str = f"{int(x)},{int(y)}"
                    try:
                        ser.write(data_str.encode('ascii') + b'\n')
                    except Exception:
                        # on write failure, silently ignore and mark ser closed
                        try:
                            ser.close()
                        except Exception:
                            pass
                        ser = None
            else:
                ball_coords = None

            # Draw constant circle with center (320,240) and radius 210 always
            # This will be drawn on every frame
            try:
                cv2.circle(frame, (320, 240), 195, (255, 0, 0), 2)
            except Exception:
                # in case frame is smaller or some unexpected error, ignore
                pass

            # Show STM connection status overlay and ball pixel coordinates
            connected = (ser is not None and getattr(ser, "is_open", False))
            status_text = "STM: Connected" if connected else "STM: Disconnected"
            if ball_coords is not None:
                ball_text = f"Ball: {ball_coords[0]},{ball_coords[1]}"
            else:
                ball_text = "Ball: Not detected"

            # prepare stacked text (two lines)
            lines = [status_text, ball_text]
            font = cv2.FONT_HERSHEY_SIMPLEX
            font_scale = 0.8
            thickness = 2
            padding_x = 6
            padding_y = 6
            line_spacing = 8  # px between lines

            # compute widths and heights for both lines
            sizes = [cv2.getTextSize(ln, font, font_scale, thickness)[0] for ln in lines]
            widths = [s[0] for s in sizes]
            heights = [s[1] for s in sizes]
            max_width = max(widths)
            total_height = sum(heights) + (len(lines) - 1) * line_spacing

            # top-left corner for rectangle background
            txt_pos = (10, 30)  # baseline of first line
            rect_x1 = txt_pos[0] - padding_x
            rect_y2 = txt_pos[1] + padding_y  # baseline + padding bottom for first line
            # compute top y for rectangle: move up by heights[0] and subsequent lines
            rect_y1 = txt_pos[1] - heights[0] - padding_y
            # extend rectangle for additional lines below first
            if len(lines) > 1:
                rect_y2 = rect_y2 + (total_height - heights[0])

            # ensure rectangle covers full width
            rect_x2 = txt_pos[0] + max_width + padding_x

            # draw background rect
            cv2.rectangle(frame, (rect_x1, rect_y1), (rect_x2, rect_y2), (0, 0, 0), -1)

            # draw each line
            y_offset = txt_pos[1]
            for i, ln in enumerate(lines):
                # choose color for the status line only
                if i == 0:
                    color = (0, 255, 0) if connected else (0, 0, 255)
                else:
                    color = (255, 255, 255)  # white for ball coords
                cv2.putText(frame, ln, (txt_pos[0], y_offset), font, font_scale, color, thickness, cv2.LINE_AA)
                # increment y_offset by height of this line + spacing
                y_offset += heights[i] + line_spacing

            cv2.imshow("Frame", frame)
            key = cv2.waitKey(1) & 0xFF
            # If user presses 'q' or ESC, break
            if key == ord('q') or key == 27:
                break

    except Exception:
        # silent on any unexpected exception
        pass

    finally:
        cleanup(cap, ser)
